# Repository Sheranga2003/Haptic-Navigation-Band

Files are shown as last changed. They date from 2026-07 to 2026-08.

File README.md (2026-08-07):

# Haptic Navigation Band
A wearable device that uses distance sensing to give haptic (vibration) feedback about nearby obstacles — built as a low-cost assistive navigation aid concept for visually impaired users.

## 🎥 Demo
*(Coming soon — build in progress)*

## 💡 The Problem
Traditional canes only detect obstacles at ground level and require physical contact. This project explores whether distance-based haptic feedback — closer object = stronger/faster vibration — can give a wearer a sense of their surroundings without sound or contact.

## 🛠️ How It Works
1. A distance sensor continuously scans for nearby objects
2. Distance readings are mapped to vibration intensity/frequency
3. The wearer feels stronger, faster vibration as they approach an obstacle — no vibration means no obstacle in range

## 📦 Hardware
| Component | Purpose |
|---|---|
| Arduino Nano | Microcontroller |
| HC-SR04 (early prototype) → TF-Luna LiDAR (final) | Distance sensing |
| ERM coin vibration motor (10mm, 3V) | Haptic feedback |
| 2N2222 / S8050 transistor + 1N4001 diode | Motor driver circuit |
| 3D printed enclosure (Fusion 360) | Wearable housing |
| 3.7V LiPo battery + TP4056 charger + boost converter | Portable power (planned) |

## 🔌 Circuit Diagram
**Final wiring (Nano + TF-Luna LiDAR + vibration motor):**
Final circuit

**Earlier prototype (Uno + ultrasonic + LED):**
LED test circuit

## 🧊 CAD Files
- [Enclosure body (STL)](./Haptic%20Band%20V2%20Body.stl)
- [Enclosure cover (STL)](./Haptic%20Band%20V2%20Cover.stl)

## 💻 Code
See [`/code`](./code) for Arduino sketches:
- `ultrasonic_led_test.ino` — early prototype, LED stands in for motor
- `lidar_motor_final.ino` — final LiDAR-based version

## 📈 Development Log
- **07/25/2026** — Prototyped distance-to-blink-rate logic with HC-SR04 + LED on breadboard
- **07/28/2026** — Swapped LED for vibration motor, added transistor driver circuit
- **07/28/2026** — Switched sensor to VL53L1X, then TF-Luna LiDAR for better range/accuracy
- **July 29, 2026** — Debugged TF-Luna I2C wiring (bad breadboard row + MODE pin confusion caused I2C bus to hang); got full LiDAR + vibration motor pulsing pipeline working end-to-end
- **July 29, 2026** — Finalized circuit diagram and updated documentation

## 🧠 Challenges & Decisions
- *Why ERM over LRA motor:* simpler PWM control, no dedicated driver chip needed
- *Why LiDAR over ultrasonic:* narrower beam = more precise directional feedback, smaller footprint for wearable design
- *I2C debugging:* a half-connected sensor (power disconnected, but data lines still attached) silently hung the entire I2C bus, since the Wire library has no built-in timeout. Learned to fully disconnect devices when testing, not just power. Also traced a bad breadboard power row that looked connected but wasn't providing real voltage — confirmed with a direct-to-pin connection bypassing the breadboard entirely

## 🚀 Future Improvements
- Multiple sensors for directional feedback (left/right/front)
- Bluetooth logging via ESP32 for a companion app
- Battery-powered standalone wearable version

## 📷 Build Photos
*(breadboard → enclosure → final assembly, in order)*

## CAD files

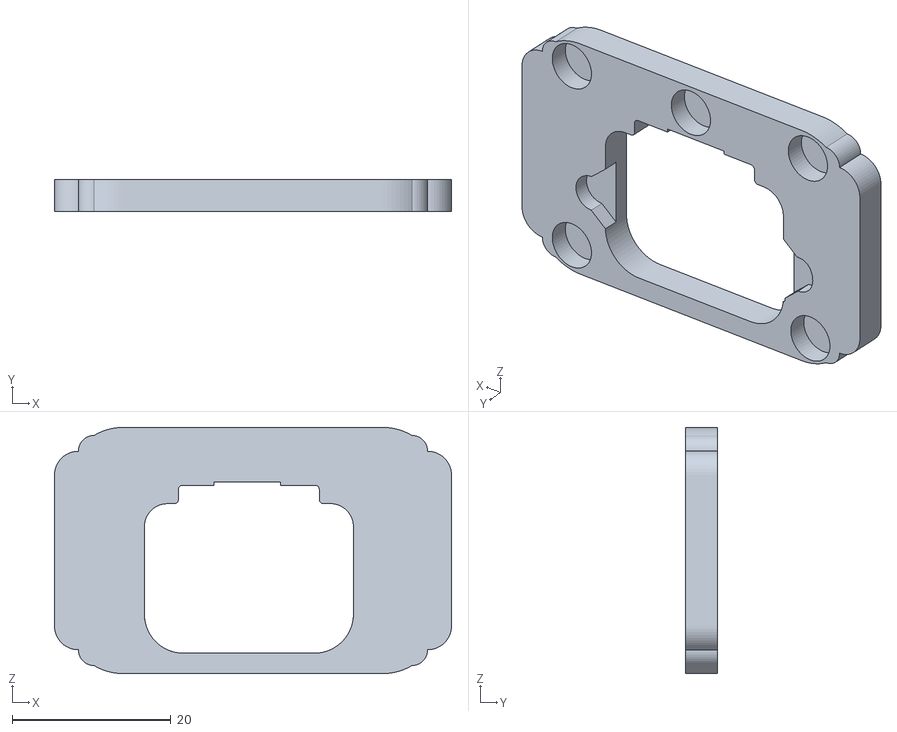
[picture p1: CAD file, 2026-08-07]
Haptic Band V2 Cover.stl
50.0 x 4.00 x 31.0

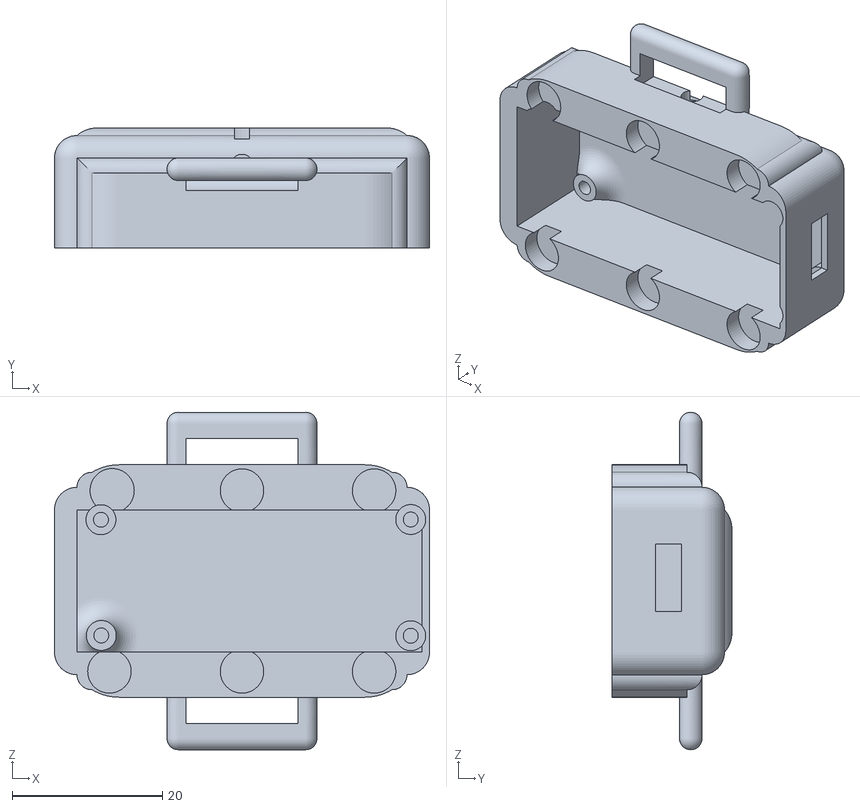
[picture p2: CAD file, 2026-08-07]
Haptic Band V2 Body.stl
50.0 x 16.0 x 45.0

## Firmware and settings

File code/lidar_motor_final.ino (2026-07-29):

// TF-Luna LiDAR -> Vibration Motor (pulsing haptic feedback)
// Wiring (Arduino Nano):
//   TF-Luna Pin 1 (5V)      -> Nano 5V
//   TF-Luna Pin 2 (SDA)     -> Nano A4
//   TF-Luna Pin 3 (SCL)     -> Nano A5
//   TF-Luna Pin 4 (GND)     -> Nano GND
//   TF-Luna Pin 5 (GND/I2C) -> Nano GND (enables I2C mode)
//   Motor -> D6 (through transistor circuit)
//
// Requires the "TFLI2C" library (by Bud Ryerson) - install via Library Manager

#include <Wire.h>
#include "TFLI2C.h"

TFLI2C tflI2C;
int16_t tfDist;
int16_t tfAddr = TFL_DEF_ADR; // default I2C address 0x10

const int motorPin = 6;

const float standbyThreshold = 120.0; // cm - beyond this, motor is OFF
const float minDistance = 20.0;       // cm - TF-Luna's practical close range

const int slowestPulseInterval = 600; // ms between pulses when just entering range
const int fastestPulseInterval = 80;  // ms between pulses when very close

const int weakestVibration = 120;     // PWM value for far pulses (above motor's dead zone)
const int strongestVibration = 255;   // PWM value for close pulses

unsigned long lastPulseTime = 0;
bool motorOn = false;

void setup() {
  pinMode(motorPin, OUTPUT);
  analogWrite(motorPin, 0);

  Serial.begin(115200);
  Wire.begin();
}

void loop() {
  float distanceCm = readDistanceCm();

  if (distanceCm <= 0 || distanceCm > standbyThreshold) {
    analogWrite(motorPin, 0);
    motorOn = false;
    Serial.println("No object detected - motor off");
    return;
  }

  distanceCm = constrain(distanceCm, minDistance, standbyThreshold);

  int currentPulseInterval = map(distanceCm, minDistance, standbyThreshold,
                                  fastestPulseInterval, slowestPulseInterval);
  int vibrationStrength = map(distanceCm, minDistance, standbyThreshold,
                               strongestVibration, weakestVibration);

  unsigned long now = millis();
  unsigned long pulseOnDuration = currentPulseInterval / 3;

  if (!motorOn && (now - lastPulseTime >= (unsigned long)currentPulseInterval)) {
    analogWrite(motorPin, vibrationStrength);
    motorOn = true;
    lastPulseTime = now;
  } else if (motorOn && (now - lastPulseTime >= pulseOnDuration)) {
    analogWrite(motorPin, 0);
    motorOn = false;
  }

  Serial.print("Distance: ");
  Serial.print(distanceCm);
  Serial.print(" cm | Interval: ");
  Serial.print(currentPulseInterval);
  Serial.print(" ms | Strength: ");
  Serial.println(vibrationStrength);
}

float readDistanceCm() {
  if (tflI2C.getData(tfDist, tfAddr)) {
    return (float)tfDist;
  }
  return -1;
}

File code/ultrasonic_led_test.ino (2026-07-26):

// HC-SR04 -> LED blink-rate demo
// Wiring: Trig -> D9, Echo -> D10, LED (+resistor) -> D6

const int trigPin = 9;
const int echoPin = 10;
const int ledPin = 6;

const float standbyThreshold = 100.0; // cm - beyond this, LED stays solid ON
const float minDistance = 5.0;        // cm - closest realistic reading
const int slowestBlink = 500;         // ms half-period when just inside range
const int fastestBlink = 40;          // ms half-period when very close

unsigned long lastToggleTime = 0;
bool ledState = false;

void setup() {
  pinMode(trigPin, OUTPUT);
  pinMode(echoPin, INPUT);
  pinMode(ledPin, OUTPUT);
  Serial.begin(9600);
}

void loop() {
  float distanceCm = readDistanceCm();

  if (distanceCm <= 0 || distanceCm > standbyThreshold) {
    // Nothing in range -> standby mode, LED solid on
    digitalWrite(ledPin, HIGH);
    Serial.println("Standby (no object in range)");
  } else {
    // Something in range -> blink, faster as distance shrinks
    int blinkInterval = mapDistanceToBlinkInterval(distanceCm);

    unsigned long now = millis();
    if (now - lastToggleTime >= (unsigned long)blinkInterval) {
      ledState = !ledState;
      digitalWrite(ledPin, ledState ? HIGH : LOW);
      lastToggleTime = now;
    }

    Serial.print("Distance: ");
    Serial.print(distanceCm);
    Serial.print(" cm | Blink interval: ");
    Serial.print(blinkInterval);
    Serial.println(" ms");
  }
}

float readDistanceCm() {
  digitalWrite(trigPin, LOW);
  delayMicroseconds(2);
  digitalWrite(trigPin, HIGH);
  delayMicroseconds(10);
  digitalWrite(trigPin, LOW);

  long duration = pulseIn(echoPin, HIGH, 30000); // 30ms timeout
  if (duration == 0) return -1; // no echo = out of range

  return duration * 0.0343 / 2;
}

int mapDistanceToBlinkInterval(float distanceCm) {
  distanceCm = constrain(distanceCm, minDistance, standbyThreshold);
  return map(distanceCm, minDistance, standbyThreshold, fastestBlink, slowestBlink);
}

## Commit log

2026-07-26 Enhance README with project details and structure
    Expanded the README to include detailed project information, hardware components, circuit diagram, code references, development log, challenges, future improvements, and build photos.
2026-07-26 add ultrasonic LED test code
2026-07-26 add circuit diagrams
2026-07-26 Add circuit diagrams and code section to README
    Updated README to include circuit diagrams and code references.
2026-07-26 Revise circuit diagrams in README
    Updated circuit diagram section to include prototype and final LiDAR diagrams.
2026-07-26 Replace ultrasonic circuit image with LED test circuit
    Updated the circuit diagram image for the prototype section.
2026-07-26 Enhance README with circuit diagrams and code section
    Updated README.md to include circuit diagrams and code location.
2026-07-29 add working TF-Luna + motor haptic feedback code
2026-07-29 Revise hardware and circuit documentation in README
    Updated hardware components and circuit diagrams in the README. Added details about the Arduino Nano and TF-Luna LiDAR, and revised the documentation for clarity.
2026-07-29 Update README to remove ultrasonic_motor.ino
    Removed reference to ultrasonic_motor.ino from the README.
2026-08-07 add v3 enclosure STL files
    [Haptic Band V2 Body.stl, Haptic Band V2 Cover.stl]
2026-08-07 Add CAD files section to README
    Added CAD files for enclosure body and cover.
2026-08-07 Fix link to enclosure body STL file
